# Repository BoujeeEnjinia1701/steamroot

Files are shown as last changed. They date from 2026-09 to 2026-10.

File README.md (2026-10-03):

# SteamRoot

     

**Area:** Agriculture · **TRL:** 3 of 9 (analytical proof of concept on paper) · **Value-engineering target:** USD 2,200 (estimated cost USD 2,600) · **Difficulty:** 5 of 5

Low-pressure, biomass-fired steam generator with a flue-gas economizer and a steam-hood trailer for soil pasteurization, operated near atmospheric pressure to stay out of pressure vessel code.

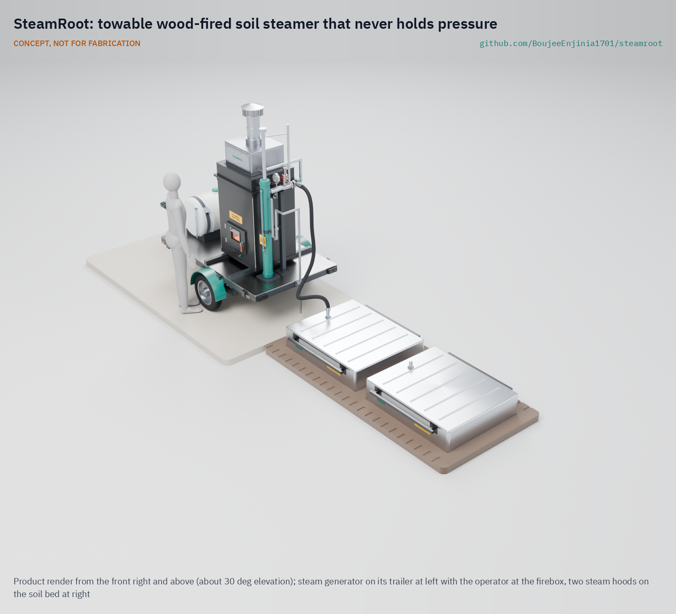
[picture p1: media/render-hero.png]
SteamRoot: towable wood-fired soil steamer that never holds pressure, product render


[Exploded render](media/render-exploded.png) · [Detail render](media/render-detail.png) · [Interactive 3D model](media/viewer.html) · [Concept blueprint (PDF)](media/concept-blueprint.pdf) · [General arrangement STR-DWG-002 (PDF)](cad/drawings/STR-DWG-002.pdf) · [Sizing calculations](docs/04-calcs/01-sizing.md) · [Prototype build plan](docs/05-build-plan.md) · [Design decisions](docs/06-design-decisions.md) · [Review note](docs/REVIEW.md)

## Concept rationale

Steam is the one soil treatment that kills weed seeds and soil-borne pathogens in hours, in any season, with nothing left behind in the soil. What keeps it away from small growers is the boiler: a pressurized, diesel- or gas-fired vessel that is costly, regulated and dangerous to improvise. SteamRoot removes the pressure instead of managing it. A once-through coil holds about 7 L of water and is always open to the air through a water seal, so there is no drum to rupture, and the fire burns the prunings and scrap wood that most farms already have.

The design is open and garage-buildable because the users are market gardens, nurseries and cooperatives that cannot justify a commercial steamer for a few hundred square meters of beds. Stock steel, stainless tube, a used trailer and certified off-the-shelf safety parts keep it inspectable and repairable, and publishing the calculations lets extension services and local boiler authorities check exactly how it stays near atmospheric pressure.

## Burning platform

Weeds are the costliest pest group in farming: a global review found they cause the highest potential crop loss of any pest group, about 34 % ([Oerke, *Journal of Agricultural Science*, 2006](https://www.cambridge.org/core/journals/journal-of-agricultural-science/article/abs/crop-losses-to-pests/AD61661AD6D503577B3E73F2787FE7B2)). Growers who avoid synthetic herbicides are a large and growing group: certified organic land reached 98.9 million hectares at the end of 2023, managed by 4.3 million producers ([FiBL and IFOAM, *The World of Organic Agriculture 2025*](https://www.fibl.org/en/info-centre/news/organic-market-back-on-track)).

The chemical fallback is closing. Methyl bromide, long the standard soil fumigant, was phased out under the Montreal Protocol; in the United States, California strawberry fields were the last pre-plant use to receive a critical use exemption, for 2016, and no pre-plant use was nominated for 2017 ([US EPA, 80 FR 61985, 2015](https://www.federalregister.gov/documents/2015/10/15/2015-26301/protection-of-stratospheric-ozone-the-2016-critical-use-exemption-from-the-phaseout-of-methyl)). Steam is an effective replacement, but only if its energy cost per square meter comes down.

## Where it could be used

### By industry

| Industry | Use |
| --- | --- |
| Organic market gardening | Clearing weed seed banks from high-value vegetable beds before planting |
| Nurseries and seedling propagation | Pasteurizing potting media and propagation beds against damping-off |
| Greenhouse and polytunnel horticulture | Steaming soil between crops, with the generator kept outside |
| Cut flowers and ornamentals | Soil treatment for field-grown flowers where fumigants are no longer allowed |
| Agricultural extension and research | An open reference design for field days, trials and teaching |
| Community gardens and urban farms | A shared, towable machine for plots too small for contract steaming |

### By country or region

| Country or region | Why it matters there |
| --- | --- |
| United States (California) | High-income strawberry and vegetable growers lost the last pre-plant methyl bromide exemption after 2016 ([US EPA, 2015](https://www.federalregister.gov/documents/2015/10/15/2015-26301/protection-of-stratospheric-ozone-the-2016-critical-use-exemption-from-the-phaseout-of-methyl)) |
| Mexico | Steam has already replaced methyl bromide in the ornamental plant sector, where growers pasteurize media before planting ([UNEP, 2014](https://ozone.unep.org/system/files/documents/Phasing-out%20Methyl%20Bromide%20in%20developing%20countries%20FINAL%20low%20version.pdf)) |
| India | Home to 2.36 million organic producers, more than half the world total ([FiBL, 2025](https://www.fibl.org/en/info-centre/news/organic-market-back-on-track)) |
| Kenya | Substrates replaced methyl bromide in Kenyan rose production; growers who stay in soil, and nursery beds, still need a clean soil treatment ([UNEP, 2014](https://ozone.unep.org/system/files/documents/Phasing-out%20Methyl%20Bromide%20in%20developing%20countries%20FINAL%20low%20version.pdf)) |
| Egypt and Jordan | Methyl bromide phase-out projects there used soil solarization, which needs the hot season; steam works year-round ([UNEP, 2014](https://ozone.unep.org/system/files/documents/Phasing-out%20Methyl%20Bromide%20in%20developing%20countries%20FINAL%20low%20version.pdf)) |

## What sparked the idea

The idea traces back to the Montreal Protocol's phase-out of methyl bromide as a soil fumigant, completed on 1 January 2005 in developed countries and on 1 January 2015 in developing ones. Reviewing that phase-out in 2014, UNEP's Ozone Secretariat called steam "probably the best technical alternative to MB in protected agriculture", but warned that deep in-ground steaming needs so much boiler time, labor and fuel that it "may render steaming an economically unacceptable alternative" ([UNEP, *Phasing-out Methyl Bromide in Developing Countries*, 2014](https://ozone.unep.org/system/files/documents/Phasing-out%20Methyl%20Bromide%20in%20developing%20countries%20FINAL%20low%20version.pdf)). SteamRoot starts from that gap: keep the steam, and cut the boiler cost, the fuel bill and the pressure hazard.

## Problem

Herbicide-free weed and pathogen control by steaming soil works, but the portable boilers that do it are inefficient and diesel-fired.

## Concept

Low-pressure, biomass-fired steam generator with a flue-gas economizer and a steam-hood trailer for soil pasteurization, operated near atmospheric pressure to stay out of pressure vessel code.

Full design precis: [docs/02-concept.md](docs/02-concept.md)

TRL 3 status (paper only): the sizing note [STR-CAL-001](docs/04-calcs/01-sizing.md) finds 30 kg/h of steam at a header pressure of about 0.03 bar with 7.3 L of water in the heated section, about 1.9 m²/h treated at 15 cm with two hoods and 499 kg as towed with the tank drained and both hoods aboard. With the evaporator bank and the primary and secondary air dampers decided on 2026-10-02, fuel-to-steam efficiency is about 69 % against the 65 % target (about 61 % if the dampers are left open) and wood use is 4.2 kg per m² against 4. Value-engineering target: USD 2,200. Estimated cost of the constructable design: USD 2,600 (USD 400 over the target). A written ruling from the local boiler authority is an open prerequisite before any detail design or build. TRL 4 work is on hold.

## Key components

- Once-through monotube coil, 25.4 mm 316 stainless
- Fiber-lined firebox
- Evaporator bank and economizer in the flue, with primary and secondary air dampers
- Fixed-rate feed pump with coil outlet and tank level alarms
- Water-seal vent with an overflow and loop seal, and a certified relief valve
- Two steam hoods used alternately
- Thermocouples

The working bill of materials is in [bom/bom.csv](bom/bom.csv).

## Building the prototype

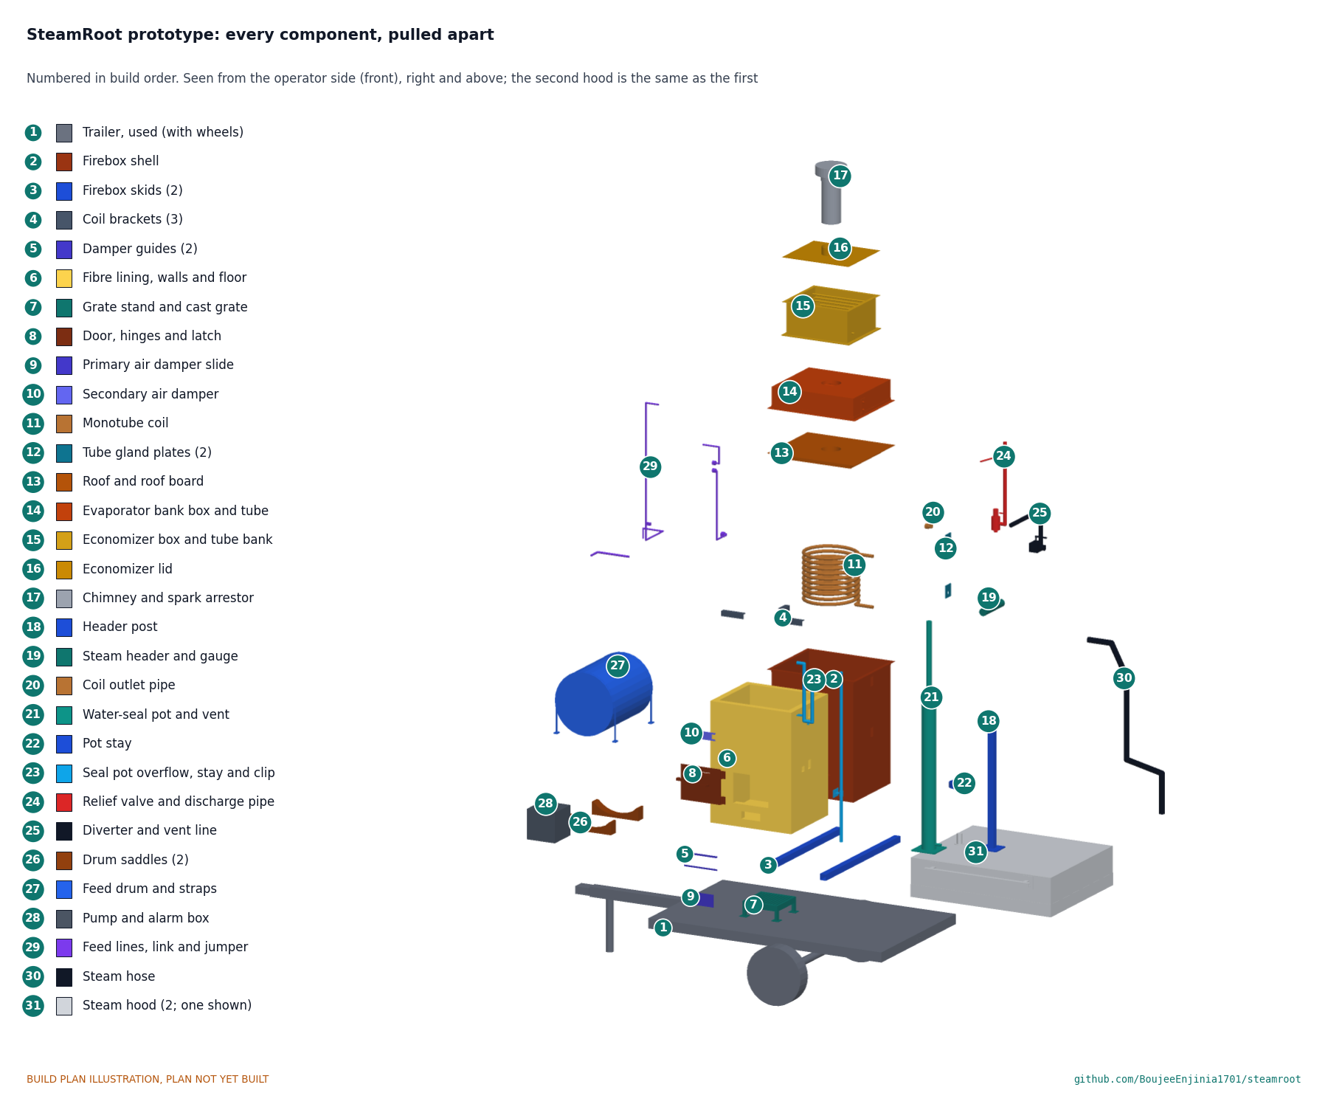
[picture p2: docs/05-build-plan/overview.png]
SteamRoot prototype: every component pulled apart and numbered in build order


The [prototype build plan](docs/05-build-plan.md) (STR-BLD-001) shows, in pictures, how to make each of the 31 components and put them together in twenty steps; nothing has been built, and nothing may be until the local boiler authority has given its written ruling. The firebox, roof, skids, brackets, grate stand, door, dampers, evaporator bank box, economizer, header, post, seal pot and overflow are cut and welded from mild steel and stainless sheet, tube and pipe; the coil and the evaporator bank are each bent from one length of stainless tube; the hoods are folded and riveted. Writing the plan made the design buildable: the firebox grew to about 1 m so the door and fire sit below the coil, the roof now bolts on so the coil can be fitted, the seal pot's dip leg was shortened, and supports, glands, feed lines and a vent line were added (STR-DDR-003, accepted by Amish on 2026-10-02). The decisions of 2026-10-02 then added the evaporator bank box, the secondary air damper, a seal pot overflow that holds the seal limit at 0.084 bar, and hood handles that can carry ballast. Every picture is drawn from the model, and the model checks that each part touches what it should and clears what it should not; open decisions are in the [design decisions register](docs/06-design-decisions.md).

## Safety

> This design involves open fire, carbon monoxide and steam. Keep operating pressure and water volume below local boiler and pressure vessel code thresholds, get a written ruling from the local boiler authority before any build, fit a certified relief valve, and never operate it unattended.

## Repository layout

| Folder | Contents |
| --- | --- |
| `docs/` | Problem, concept, requirements, calculations and design decisions |
| `cad/src/` | build123d Python source, the source of truth for all geometry |
| `cad/step/`, `cad/stl/` | Exported models for FreeCAD, other CAD tools and printing |
| `cad/drawings/` | 2D sketches and dimensioned drawings |
| `bom/` | Bill of materials |
| `electronics/` | KiCad schematics and PCB layouts |
| `firmware/` | Microcontroller code |
| `media/` | Renders, perspectives and photos |
| `build-log/` | Dated prototyping notes |

## Documentation

Controlled documents follow the portfolio [documentation standard](.kit/STANDARDS.md). Each carries a document ID (STR-PRC-001 for the precis), a version and a revision history. Branded PDFs are built with `python .kit/render.py` and attached to GitHub Releases when a document is tagged, for example `STR-PRC-001/v1.0`.

## Credits

Designed by Amish Chadha. See [CONTRIBUTORS.md](CONTRIBUTORS.md) for roles. To cite this design, use [CITATION.cff](CITATION.cff) (GitHub shows it as "Cite this repository").

AI assistance (Claude) was used to accelerate concept renders, prototype documentation and first-pass sizing calculations. Design direction and all decisions are Amish Chadha's, recorded in this repository's decision records (`docs/decisions/`).

## Licenses

- **Hardware** (CAD, drawings, BOM, electronics): [CERN-OHL-S v2](LICENSE)
- **Software** (firmware, scripts, notebooks): [MIT](LICENSE-SOFTWARE)

A project of the [Design Molecule](https://designmolecule.com) lab.

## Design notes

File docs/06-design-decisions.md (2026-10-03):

---
doc_id: STR-DEC-001
title: SteamRoot design decisions register
project: SteamRoot
doc_type: Design decisions register
version: "0.4"
status: Draft
date: '2026-10-03'
author: Amish Chadha
license: CERN-OHL-S-2.0
revisions:
- version: "0.1"
  date: '2026-10-01'
  author: Amish Chadha
  change: Register opened with the open decisions from the review notes, the decision records and the build plan work; budget treated as a value-engineering target
- version: "0.2"
  date: '2026-10-02'
  author: Amish Chadha
  change: "Amish approved the recommendations for all eleven open decisions on 2026-10-02 (STR-DDR-003 accepted); moved to decisions made"
- version: "0.3"
  date: '2026-10-02'
  author: Amish Chadha
  change: "Approved decisions carried into the design (STR-CAL-001 v0.4); value engineering restated at USD 2,600; two new proposals opened: R4 restatement and the R11 mass basis"
- version: "0.4"
  date: '2026-10-03'
  author: Amish Chadha
  change: "Amish accepted the cost overrun against the value-engineering target on 2026-10-03; row added to decisions made; value engineering section updated"
---

# SteamRoot design decisions register

Every design decision still to be made, and every decision made, in one place. Each decision is argued in full in its decision record under `docs/decisions/`; this register is the index Amish works from. The build plan (`docs/05-build-plan.md`) describes the design as it stands and does not list open decisions.

> **Safety:** Decision 1 gates everything else. No part of SteamRoot may be bought, built or fired before the written ruling from the local boiler authority exists, and that ruling overrides any decision here that it is stricter than.

## Open decisions

The eleven decisions of the 2026-10-02 sign-off are made. Carrying them into the design raised two new questions, proposed here and awaiting Amish.

| # | Question | Options | Recommendation | Source |
| --- | --- | --- | --- | --- |
| 12 | Restate R4 (wood per m² at 15 cm), as planned on 2026-10-02. With the bank and dampers the design uses 4.2 kg/m² (4.7 kg/m² with the dampers open); 4 kg/m² needs about 72 % efficiency. | (a) 4.5 kg/m² or less with the dampers set; (b) 5.0 kg/m² or less, which also covers open dampers; (c) keep 4 kg/m² and seek the rest in lower steam demand | (a): met with 7 % margin and still rewards air control. Proposed, awaiting Amish | STR-CAL-001 v0.4, section 4 |
| 13 | R11 is now at risk at 499 kg as towed, because the bank, overflow and steel handles added 36 kg. The hoods ride on a second vehicle for the prototype (decided 2026-10-02). | (a) count R11 without the hoods, as they are towed: 437 kg; (b) keep the hoods in R11 and save mass elsewhere (lighter bank box, aluminium skids); (c) restate R11 | (a), since it follows the decision already made; record it in STR-REQ-001. Proposed, awaiting Amish | STR-CAL-001 v0.4, section 7 |

## To confirm when parts are bought

| # | What to confirm | Why it matters | Source |
| --- | --- | --- | --- |
| 1 | The used trailer: rated 750 kg or more, axle rated for the 633 kg full mass, and side rails that take an M12 bolt 40 mm in from the deck edge (80 mm rails assumed) | The skids bolt into the side rails; the full machine weighs 602 kg on site | STR-DDR-003, C5; STR-CAL-001 |
| 2 | The relief valve's rated capacity, 375 lb/h (170 kg/h) or more at 15 psi, on the valve actually bought, with its code stamp | R9 is met only on the maker's table | STR-DDR-002, item 4 |
| 3 | The three-way diverter cannot stop in a position that closes both outlets, and is rated for saturated steam | The open vent must never be isolated | STR-PRC-001; STR-DDR-003, C8 |
| 4 | The steam hose and couplings are rated for saturated steam (not hot water), with whip checks | Burn hazard at the hose | BOM line 11 |
| 5 | The cast grate is 300 x 300 mm; if not, the grate stand is resized to suit | The stand is made to the grate | STR-DDR-003, C1 |
| 6 | The ceramic fibre blanket and board are rated for 1260 °C, with rigidizer for the walls | The lining faces the fire | BOM line 5 |
| 7 | The feed pump's shut-off pressure is 3 bar or less | It caps the coil inlet pressure if the coil blocks | STR-CAL-001, section 6 |
| 8 | The alarm controller takes a type K thermocouple and drives a relay; the float switch trips with about 20 L left | The dry-coil and low-tank alarms | BOM line 16 |

## Value engineering

Value-engineering target: USD 2,200 (a hypothetical control target, not a limit). Estimated cost of the constructable design: USD 2,600 (USD 400 over the target). Main cost drivers and savings worth trying:

Amish accepted this overrun on 2026-10-03: the estimated cost of USD 2,600 against the USD 2,200 target (USD 400 over). Amish: "Cost over target - i accept all the cost variations and overruns". It stays reported against the target as an accepted overrun, and the savings below remain worth trying.

- The largest lines are the two hoods (USD 310 together), the firebox (USD 265), the header and water-seal assembly with its overflow (USD 220), the stainless coil (USD 215), the used trailer (USD 200), the evaporator bank (USD 190) and the steam hose (USD 180).
- Carrying the 2026-10-02 decisions into the design added USD 325: the evaporator bank (USD 190), the seal pot overflow (USD 70), the bank link and reducing unions (USD 45), ballast-rated hood handles (USD 30), the secondary damper and fixings (USD 10 net), less USD 20 for one coil turn fewer.
- Making the design constructable added USD 360: the taller firebox and longer coil (USD 55), steelwork for the skids, post, stay and saddles (USD 70), firebox internals and glands (USD 50), feed lines and stainless fittings (USD 95), the relief discharge and vent line (USD 45) and fixings and straps (USD 45).
- Savings worth trying: copper instead of stainless for the cold feed line from the pump (about USD 20; the economizer and jumper stay stainless); offcut or reclaimed steel for the skids, post and stand; buying the stainless fittings from one supplier as a kit; a used trailer that already has cross members for the skids; welded rather than seamless 316 tube for the bank (already assumed); a bank box with 1.5 mm walls. The safety parts (relief valve, diverter, hose, seal and vent) are not candidates for savings.

## Decisions made

| Date | Decision | Decided by | Record |
| --- | --- | --- | --- |
| 2026-09-25 | Open-vented steam side with a water-seal vent and a certified relief valve, no isolating valve; 25.4 mm 316 stainless monotube coil; two hoods used alternately; fixed-rate feed with coil outlet and tank level alarms; budget USD 1,800; first users one market garden and one nursery, first jurisdiction Amish's home jurisdiction; get the boiler authority ruling first | Amish: "proceed with all of your recommendations across all batches. Make sure we don't proceed to TRL 4 on any of them." | STR-DDR-001 |
| 2026-09-25 | Wood only, no liquid fuel backup | Amish: go with recommendation | STR-DDR-001, item 10; STR-DDR-002, item 9 |
| 2026-09-25 | Keep the R5 and R4 targets and study an evaporator bank with controlled air; R2 restated to about 1.9 and 3.4 m²/h; R6 split into 0.1 bar at the header and 0.15 bar at the coil inlet; R9 worded as 15 psi (1.03 bar) or less and sized for the refeed flash; R11 as towed with the drum drained; budget USD 2,200; fibre lining; one hose moved between the hoods | Amish: "i accept all your recommendations, go with them across all repos." | STR-DDR-002, items 1 to 8 |
| 2026-10-01 | The budget is a value-engineering target, not a limit; cost is reported over or under it | Amish: "the budgets are a hypothethical control target to ensure we are thinking along a value engineering lens. its ok to ensure wording reflects that the hypothesis budget was x - the real cost being accrued is y" | This register; STR-CAL-001 v0.3 |
| 2026-10-02 | The written ruling stays the gate: it is obtained before any purchase or build, the design is reviewed against it, and anything stricter it requires is adopted (the ruling itself is not yet obtained) | Amish: "i approve your recommendations for all 555 open decisions." | STR-DDR-001, item 7; STR-DDR-002, item 10 |
| 2026-10-02 | Home jurisdiction: Texas. The written ruling is asked of the Texas Department of Licensing and Regulation's boiler program | Amish: "i approve your recommendations for all 555 open decisions." | STR-DDR-002, item 11 |
| 2026-10-02 | First co-design partners: one market garden and one nursery within driving distance of Irving that already steam, solarize or chemically treat soil, found through Texas A&M AgriLife Extension's horticulture contacts (none is named or agreed yet) | Amish: "i approve your recommendations for all 555 open decisions." | STR-DDR-002, item 12 |
| 2026-10-02 | In the next paper iteration, size the evaporator bank with primary and secondary air dampers so the heated water stays at 8 L or less (smaller-bore bank tube or fewer firebox turns), without relaxing R7; plan to restate R4, since even 65 % efficiency leaves it short (about 72 % needed) | Amish: "i approve your recommendations for all 555 open decisions." | STR-DDR-002, item 1 |
| 2026-10-02 | Option (c), keeping (a) for now: the taller firebox's 51.4 % is accepted for the first prototype, and the firebox is reshaped inside the evaporator bank study | Amish: "i approve your recommendations for all 555 open decisions." | STR-DDR-003, A1 |
| 2026-10-02 | Seal pot overflow at the static water mark, piped down to ground level at the back of the trailer away from the operator's side | Amish: "i approve your recommendations for all 555 open decisions." | STR-DDR-003, A2; STR-PRC-001 open questions |
| 2026-10-02 | Relief valve discharge kept rising to 2.3 m beside the vent, with its low-point drain, subject to the authority's ruling | Amish: "i approve your recommendations for all 555 open decisions." | STR-DDR-003, A3 |
| 2026-10-02 | Seal pot drained through its valve after every day of use and whenever frost is forecast; a pre-start check that the pot is free of ice and filled to its mark | Amish: "i approve your recommendations for all 555 open decisions." | STR-PRC-001 open questions |
| 2026-10-02 | The two hoods ride on a second vehicle for the prototype | Amish: "i approve your recommendations for all 555 open decisions." | STR-PRC-001 open questions |
| 2026-10-02 | Design for construction accepted: changes C1 to C14 of STR-DDR-003 as made, with the seal pot overflow decided separately (item 6) | Amish: "i approve your recommendations for all 555 open decisions." | STR-DDR-003 |
| 2026-10-02 | Hood ballast, skirt depth or steam rate decided from TRL 4 soil tests, with skirt leakage measured at the hood edge; the hood handles are sized to take ballast weights so no redesign is needed later | Amish: "i approve your recommendations for all 555 open decisions." | STR-CAL-001, section 2; STR-PRC-001 open questions |
| 2026-10-03 | Cost overrun accepted: the estimated cost of USD 2,600 against the USD 2,200 target (USD 400 over) | Amish: "Cost over target - i accept all the cost variations and overruns" | [REVIEW.md](REVIEW.md), session 2026-10-03 |

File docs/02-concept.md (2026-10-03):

---
doc_id: STR-PRC-001
title: SteamRoot design precis
project: SteamRoot
doc_type: Design precis
version: "0.7"
status: Draft
date: '2026-10-02'
author: Amish Chadha
license: CERN-OHL-S-2.0
revisions:
- version: "0.1"
  date: '2026-09-24'
  author: Amish Chadha
  change: Initial scaffold
- version: "0.2"
  date: '2026-09-24'
  author: Amish Chadha
  change: Populate to TRL 2 (architecture, components, first-order numbers, safety, media)
- version: "0.3"
  date: '2026-09-25'
  author: Amish Chadha
  change: TRL 3 update; record Amish's 2026-09-25 decisions; replace first-order numbers with STR-CAL-001 results; water-seal pot, two hoods and alarms added; regulatory ruling marked as an open prerequisite
- version: "0.4"
  date: '2026-09-25'
  author: Amish Chadha
  change: Recommendations accepted by Amish (DDR-002)
- version: "0.5"
  date: '2026-10-01'
  author: Amish Chadha
  change: Figures and description updated for the constructable design (STR-DDR-003, STR-CAL-001 v0.3); cost against the value-engineering target; build plan and decisions register linked
- version: "0.6"
  date: '2026-10-02'
  author: Amish Chadha
  change: "Decisions of 2026-10-02: authority named, first co-design partner route, seal pot overflow and freezing rule, hoods on a second vehicle, evaporator bank study scope, hood ballast from TRL 4 tests"
- version: "0.7"
  date: '2026-10-02'
  author: Amish Chadha
  change: "Approved decisions carried into the design (STR-CAL-001 v0.4): evaporator bank and secondary air damper added, firebox 960 mm with 10 coil turns, seal pot overflow with loop seal (seal limit 0.084 bar), ballast-rated hood handles; figures and requirement status updated"
---

# SteamRoot design precis

SteamRoot is a towable, wood-fired steam generator that never holds pressure. A pump pushes water once through an economizer, an evaporator bank in the flue and a large-bore stainless coil above the fire, the steam flows at close to atmospheric pressure through a hose to one of two insulated hoods pressed onto the soil, and primary and secondary air dampers hold the excess air near 1.5. The TRL 3 calculation (STR-CAL-001 v0.4) confirms the core safety idea on paper: 30 kg/h of steam with 7.3 L of water in the heated section and a header pressure of about 0.03 bar. With the evaporator bank and dampers decided on 2026-10-02, fuel-to-steam efficiency is about 69 % (target 65 %, met if the dampers are set) and wood use 4.2 kg per m² at 15 cm (target 4, at risk; a restatement to 4.5 is proposed). It treats about 1.9 m²/h at 15 cm with two hoods and weighs 499 kg as towed with the tank drained and both hoods aboard. Value-engineering target: USD 2,200. Estimated cost of the constructable design: USD 2,600 (USD 400 over the target). The design was made constructable on 2026-10-01 (STR-DDR-003, accepted by Amish on 2026-10-02); the prototype build plan is [docs/05-build-plan.md](05-build-plan.md) and open decisions are in [docs/06-design-decisions.md](06-design-decisions.md).

> **Safety:** SteamRoot is a concept for review, not a design to build. It combines open fire, carbon monoxide, and steam that causes severe burns in under a second. Local boiler and pressure vessel rules may apply even at low pressure. **A written ruling from the local boiler authority is an open prerequisite:** Amish approved getting it before TRL 3 detail work, and it has not been obtained. See the Safety section before any further work.

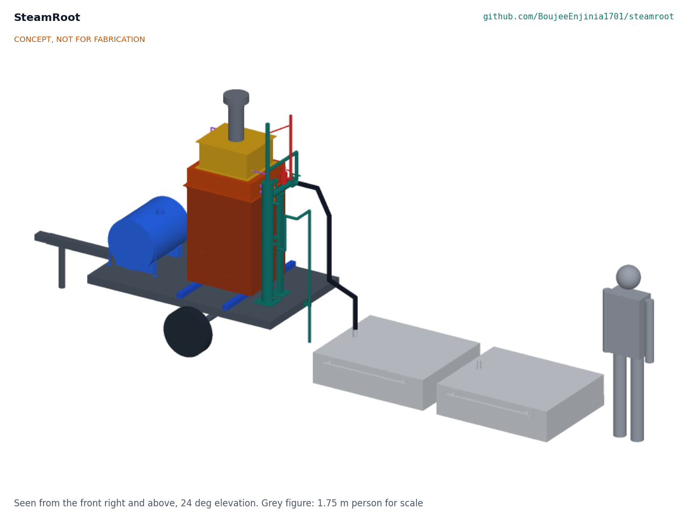
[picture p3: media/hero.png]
Hero render


*Figure 1. TRL 3 model in the working position: trailer, generator and two hoods on a bed, next to a 1.75 m person.*

## How it works

1. **Feed.** A 12 V diaphragm pump draws water from a 125 L tank and meters 0.5 L/min (30 kg/h) into the economizer at a fixed rate. A float switch warns when the tank runs low.
2. **Preheat and start to boil.** The economizer coil sits at the top of the flue and warms the feed water from about 15 °C to about 65 °C. The water then passes down through an evaporator bank, a serpentine of 15.88 mm stainless tube in a lined box on the firebox roof, where the hotter gas leaving the firebox brings it to the boil.
3. **Boil.** The warm water enters the bottom of a monotube coil that sits above the fire bed inside the fiber-lined firebox, on three brackets, with the door, grate and the two air inlets below it: primary air under the grate and secondary air through a slot in the door above the fire bed. It boils as it rises through 10 turns and leaves the top of the coil as steam. The coil holds about 5 L of water. A thermocouple on the coil outlet sounds an alarm if the outlet overheats, which is the sign of a coil running dry.
4. **Vent and separate.** The coil discharges into a steam header 1.55 m above the ground. The header is always open to the atmosphere through a water-seal pot: a dip leg reaches 890 mm below the water line. An overflow at the static water mark, piped through a 350 mm loop seal down to ground level at the back of the trailer away from the operator's side (decided by Amish, 2026-10-02), stops the pot being overfilled and lets the water the dip leg displaces run away. Steam can therefore build only about 0.084 bar gauge (890 mm of water) before it bubbles through the seal and out of a vent pipe that ends 2.3 m above the ground, above head height. The seal cannot stick or be adjusted, and it is never valved off. A certified relief valve on the header is the second line of protection.
5. **Deliver.** Steam flows through a 6 m, 25 mm steam hose to a hood. A three-way diverter at the header sends steam to the hose or to the vent and has no closed position.
6. **Pasteurize.** Each hood is a 1.2 x 1.0 m insulated open-bottom pan with a 60 mm soil skirt. Steam from a perforated manifold condenses in the soil and drives a hot front downward. While one hood heats, the other holds its soil at temperature. To change over, the operator diverts steam to the vent, moves the hose coupling to the other hood and diverts steam back.

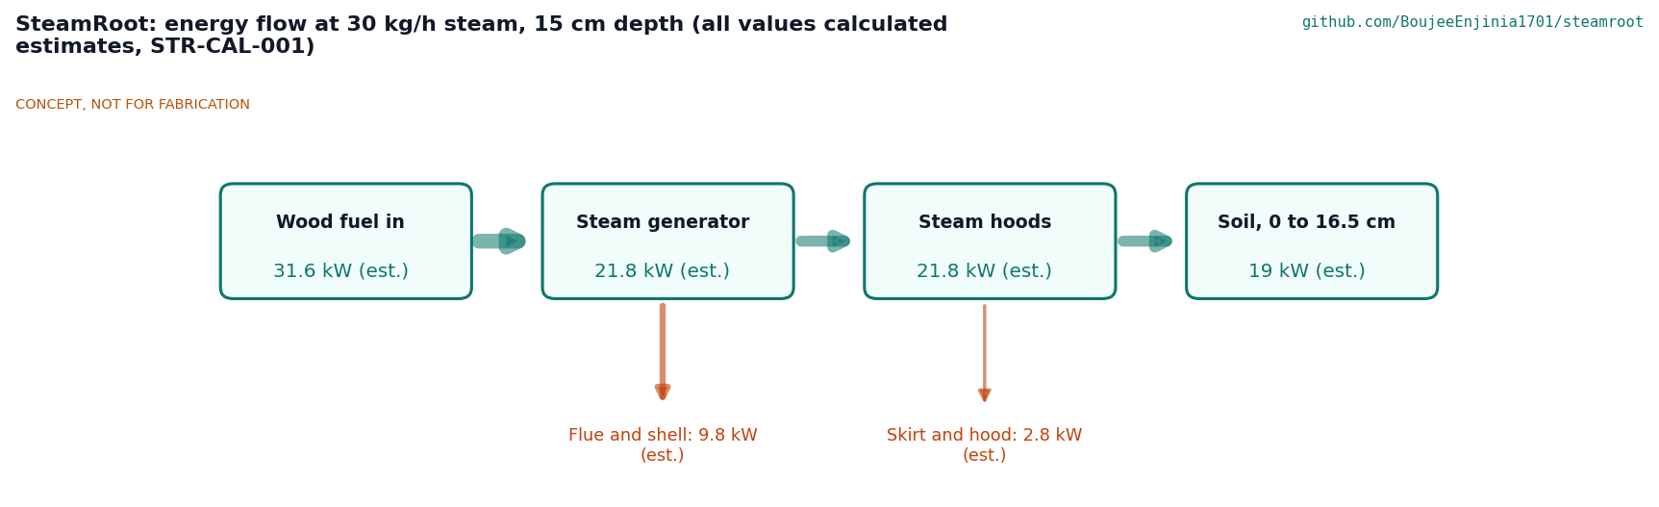
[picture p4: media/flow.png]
Energy flow


*Figure 2. Energy flow at the design point of 30 kg/h of steam and 15 cm depth. All values are calculated estimates from STR-CAL-001.*

## Main components

Item numbers match the exploded view, the general arrangement drawing STR-DWG-002 and `bom/bom.csv`. Items 13 to 16 are not drawn.

*Table 1. Main components.*

| # | Component | Choice | Notes |
| --- | --- | --- | --- |
| 1 | Trailer frame and drawbar | Used single-axle garden or utility trailer, deck 2.0 x 1.2 m | Rated 750 kg or more |
| 2 | Wheels | Trailer wheels, about 460 mm diameter | Included with the trailer |
| 3 | Feed water tank | 125 L HDPE drum with strainer and sight tube | 4.2 h of steaming |
| 4 | Feed pump | 12 V diaphragm pump with needle valve and flow meter | Its 3 bar shut-off pressure also caps coil inlet pressure if the coil blocks |
| 5 | Firebox | 700 x 600 x 960 mm steel box on two skids, bolted roof, 50 mm ceramic fiber lining, grate on a stand, latched door, primary air damper under the door and secondary air slide on the door | About 32 kW firing. A castable lining would add about 270 kg |
| 6 | Monotube steam coil | 316 stainless tube, 25.4 mm OD x 1.65 mm wall, 13.2 m in 10 turns on 420 mm | Decided by Amish, 2026-09-25; one turn fewer since 2026-10-02 to keep R7 |
| 22 | Evaporator bank | 6.4 m of 15.88 mm x 1.24 mm 316 stainless tube in two layers, in a lined 700 x 600 x 170 mm box between the roof and the economizer | Decided 2026-10-02; lifts efficiency to about 69 % with the dampers set |
| 7 | Flue-gas economizer | 7.3 m of 12.7 mm stainless tube in a box on the bank box, with condensate drain | Flue condensate is acidic (dew point about 51 °C) |
| 8 | Chimney and spark arrestor | 150 mm flue, outlet 2.4 m above ground, 6 mm mesh | Keeps flue gas above head height |
| 9 | Steam header and water-seal vent | DN50 header at 1.55 m on a post, 114 mm seal pot with an 890 mm dip leg, an overflow at the static water mark through a loop seal to the ground behind the trailer, vent to 2.3 m, three-way diverter with a vent line, quick coupling | Primary pressure limit. Decided by Amish, 2026-09-25 |
| 10 | Certified relief valve | ASME Section IV steam safety valve, 15 psi (1.03 bar) set, 3/4 in, rated 170 kg/h (375 lb/h) | Secondary protection only; sized for the dry-coil refeed flash (decided by Amish, 2026-09-25) |
| 11 | Steam hose | EPDM saturated-steam hose, 25 mm bore, 6 m, ground-joint couplings, whip checks | Steam rated, not hot-water rated |
| 12 | Steam hoods (2) | 1.2 x 1.0 x 0.25 m aluminum double-skin pans, 40 mm mineral wool, soil skirt, steel handles on foot plates sized for 40 kg of ballast | Two hoods used alternately. Decided by Amish, 2026-09-25 |
| 13 | Battery | 12 V 20 Ah sealed lead acid | Not drawn |
| 14 | Instruments | Steam gauge, four type K thermocouples and reader | Soil probes at 15 cm; not drawn |
| 15 | Safety kit | Personal CO alarm, fire extinguisher, gloves, face shield | Not drawn |
| 16 | Feed and coil alarms | Coil outlet temperature alarm, tank low-level switch | Decided by Amish, 2026-09-25; not drawn |

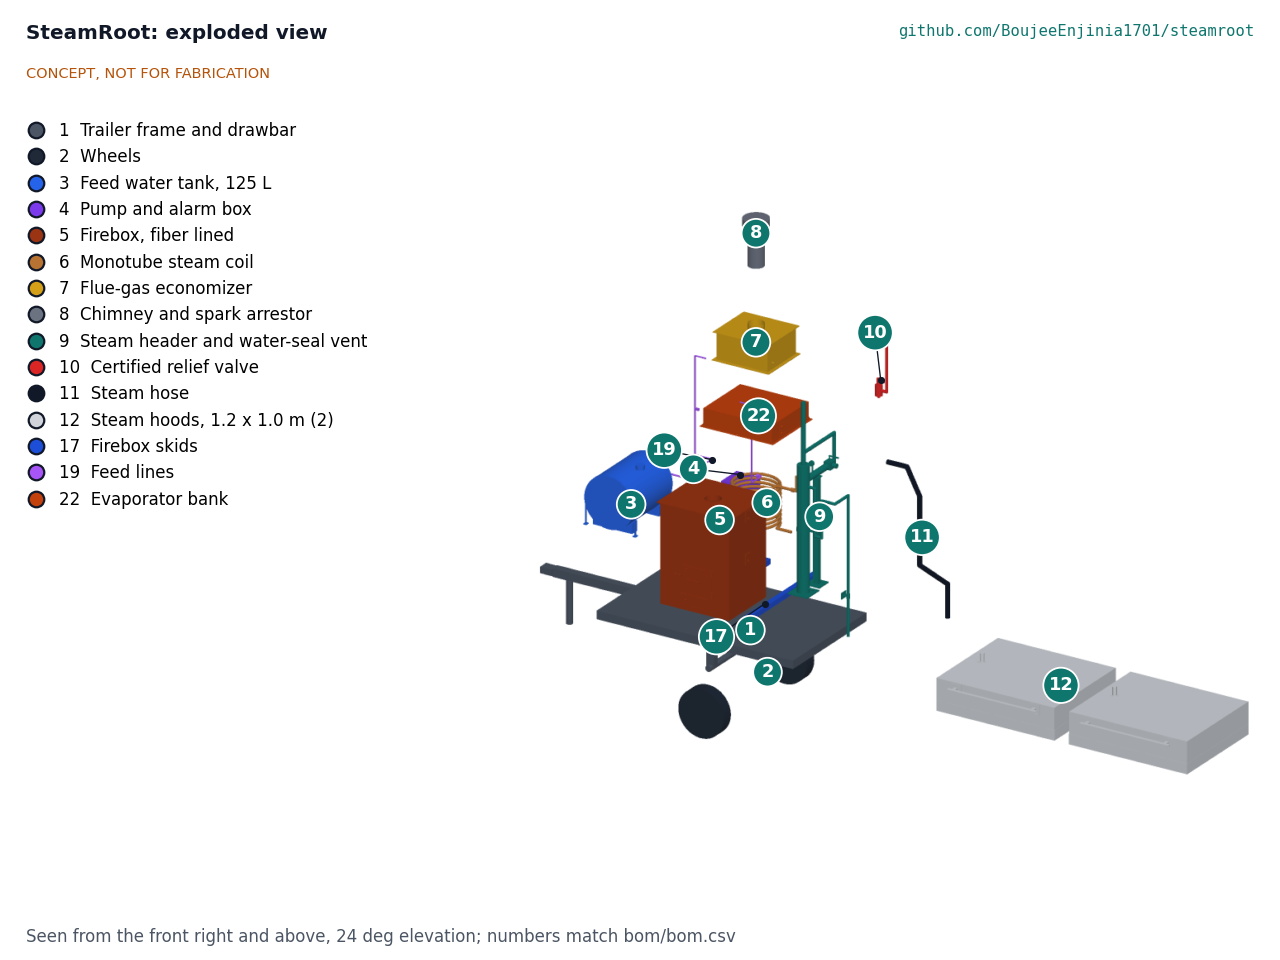
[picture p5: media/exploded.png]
Exploded view


*Figure 3. Exploded view with item numbers matching the BOM.*

## TRL 3 numbers

All values come from STR-CAL-001 (`docs/04-calcs/01-sizing.md`, script `docs/04-calcs/sizing.py`). They are paper estimates; none is tested.

*Table 2. Key results.*

| Quantity | Value | Requirement |
| --- | --- | --- |
| Steam output | 30 kg/h, firing 31.6 kW, firebox gas 510 °C | R3 met |
| Heat into the water | 21.78 kW (coil 16.91 kW, bank 3.14 kW, economizer 1.73 kW) | |
| Fuel to steam efficiency | 68.9 % at λ = 1.5 (66 % to 71 % for F = 0.25 to 0.60; 61 % with the dampers open; see STR-CAL-001, Table 6) | R5 met on paper if the dampers are set |
| Stack temperature | 235 °C | |
| Wood use | 7.9 kg/h at 14.5 MJ/kg | |
| Steam per m² at 15 cm | 15.6 kg/m² (front to 16.5 cm) | |
| Treatment rate, two hoods | 1.88 m²/h at 15 cm; 3.41 m²/h at 5 cm | R2 at risk (restated to about 1.9 and 3.4 m²/h) |
| Wood per m² at 15 cm | 4.2 kg/m² (4.7 kg/m² with the dampers open) | R4 at risk; restatement to 4.5 kg/m² proposed, awaiting Amish |
| Header pressure, normal | 0.033 bar gauge | R6 met (0.1 bar at the header) |
| Coil inlet pressure, normal (at the bank inlet) | 0.128 bar gauge | R6 met (0.15 bar at the coil inlet) |
| Water seal limit | 0.084 bar gauge with the overflow | R6 open vent met by design |
| Water in heated section, flooded | 7.32 L | R7 met |
| Steaming per fill | 4.2 h | R8 met |
| Relief valve orifice needed | 6.2 mm at 30 kg/h; 13.3 mm for a dry-coil refeed flash (138 kg/h); 3/4 in valve rated 170 kg/h | R9 met on paper |
| Chimney outlet, hood outer skin | 2.4 m; 23 °C | R10 met |
| Mass as towed, tank and seal drained | 499 kg with both hoods aboard (633 kg full; 437 kg with the hoods on a second vehicle) | R11 at risk |
| Overall width | 1.48 m | R11 at risk |
| Parts cost | USD 2,600 | USD 400 over the USD 2,200 value-engineering target |

The main performance gap was heat transfer. One coil in the firebox takes heat mostly by radiation, and without the bank the flue gas left the economizer at about 450 °C. Amish decided on 2026-09-25 to keep the 65 % target and study a convective evaporator bank with controlled air, and on 2026-10-02 to size it with primary and secondary dampers inside the 8 L limit of R7. The study in STR-CAL-001 v0.4, section 4, found that the dampers alone lift efficiency from 51 % to 61 %, and that a 6.4 m bank of smaller-bore tube with one coil turn fewer reaches about 69 % with 7.3 L of water. Efficiency now depends on the operator keeping the dampers set; with them open it falls to about 61 %. R4 needs about 72 %, so it stays just short at 4.2 kg/m².

The second gap is steam per square meter. Soil behind the steam front sits at 100 °C, not 75 °C, and the front must go 1.5 cm past the working depth to hold 70 °C through the hold. In soils finer than sand, the steam cannot be pushed through 16.5 cm of soil at full flow without lifting a 31 kg hood, so real rates may be lower still. The hood handles are sized to carry 40 kg of ballast if the TRL 4 soil tests call for it.

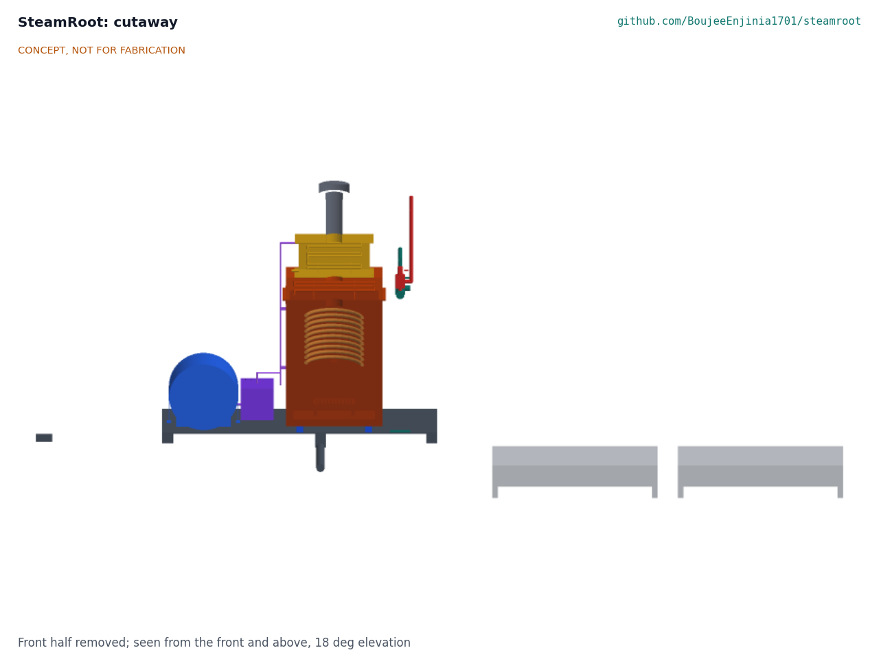
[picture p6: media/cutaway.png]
Cutaway


*Figure 4. Cutaway showing the helical coil above the fire bed inside the fiber-lined firebox, and the open-bottom hoods with their soil skirts.*

## Key design choices

- **Open-vented, never sealed.** The steam side is always open to the atmosphere through the water-seal pot and vent. There is no isolating valve between the coil and the vent, and the diverter can only send steam to the hose or the vent, never close both. Decided by Amish, 2026-09-25.
- **Monotube coil instead of a drum boiler.** A once-through coil and bank hold about 6 L of water, so a failure releases little stored energy. The cost is careful feed control: too little water dries the coil. Decided by Amish, 2026-09-25.
- **Large-bore stainless coil (25.4 mm, 316).** A 12.7 mm coil would need more than 2 bar at its inlet. The 25.4 mm coil keeps the header near 0.03 bar, though the inlet, with the bank ahead of the coil, is at about 0.13 bar. Stainless tolerates a dry-fire event far better than copper. Decided by Amish, 2026-09-25.
- **Hood steaming with two hoods used alternately.** Decided by Amish, 2026-09-25. One hose is moved between the hoods with a steam-rated coupling after steam is diverted to the vent. A second hose and a three-outlet diverter would avoid handling the hose but add at least $180. One hose: decided by Amish, 2026-09-25 (STR-DDR-002).
- **Tow drained, fill on site.** The machine is towed with the feed tank and seal pot drained (499 kg with both hoods aboard) and filled from a water supply at the site. Decided by Amish, 2026-09-25 (STR-DDR-002).
- **Relief valve sized for the refeed flash.** The 3/4 in, 15 psi valve is rated 170 kg/h, above the 138 kg/h a dry-coil refeed could produce. Decided by Amish, 2026-09-25 (STR-DDR-002).
- **Feed control.** Fixed pump rate with a coil outlet temperature alarm and a tank low-level alarm. Decided by Amish, 2026-09-25.
- **Fiber lining, not castable.** A 50 mm ceramic fiber lining keeps the firebox near 125 kg; castable refractory would make it about 406 kg and break R11. Fiber is less robust against loading damage. Fiber lining: decided by Amish, 2026-09-25 (STR-DDR-002).
- **Wood only.** Split wood or chips at 20 % moisture or drier, batch-fed by hand. No liquid fuel backup. Decided by Amish, 2026-09-25 (STR-DDR-002).

## Safety

SteamRoot is the highest-risk concept in the portfolio. Every later stage must keep this section and extend it.

> **Safety: regulatory ruling first.** A written ruling from the local boiler authority (the Texas Department of Licensing and Regulation's boiler program; Amish's home jurisdiction is Texas) on this open-vented, fired monotube coil is an open prerequisite. No detail design, build or firing may happen before it, and its ruling overrides this document if it is stricter.

> **Safety: never sealed.** The steam side must always be open to the atmosphere through the water-seal vent. Never fit a valve, cap or plug that can isolate the coil or header from the vent. Keep the seal pot filled to its mark; an empty seal pot is an open vent, but an overfilled or frozen one raises the relief pressure. The overflow at the static water mark prevents overfilling. Drain the pot through its valve after every day of use and whenever frost is forecast, and before lighting check that the pot is free of ice and filled to its mark (decided by Amish, 2026-10-02). Never plug, adjust or remove the relief valve. A sealed coil or tank over a fire can rupture violently.

> **Safety: certified relief valve.** Fit only a certified, code-stamped steam safety valve sized for the full steam output. It is a second line of protection behind the open vent, not a replacement for it. Test it by its lever as the maker directs.

> **Safety: local boiler rules.** Many jurisdictions regulate steam generators by pressure, heating surface, water volume or firing rate, and some regulate all fired steam equipment. The low-pressure design is intended to stay below common thresholds, but this is unconfirmed. Confirm with the local boiler inspector or authority before any build, and follow their ruling even if it is stricter than this document.

> **Safety: steam burns.** Steam at 100 °C releases its latent heat on skin and causes deep burns within a second. Divert steam to the vent before lifting a hood or moving the hose coupling. In fine soils steam may jet from under the hood skirt, because the soil resists steam flow more than the hood's weight can hold (STR-CAL-001, section 2). Keep hands and feet clear of the skirt and the vent outlet. Wear heat-resistant gloves, a face shield, long sleeves and closed boots. Keep bystanders, children and animals at least 5 m away. Use a steam-rated hose with a whip check, and inspect it before every use.

> **Safety: dry coil.** If the feed pump stops or the tank runs dry, the coil heats toward the firebox gas temperature (about 520 °C) while the fire keeps burning. Refeeding it could flash about 1.3 kg of water at about five times the design steam flow, more than the vent path is sized for. Never restart the feed into a hot, dry coil. Close the air damper, let the fire die and let the coil cool first. The coil outlet alarm and the tank low-level alarm exist to catch this early.

> **Safety: fire.** Operate only on bare ground or gravel, clear of dry vegetation, with a fire extinguisher and water at hand. The spark arrestor must be fitted; the flue leaves at about 450 °C. Do not operate during fire bans or in high wind. Never leave a lit firebox unattended, and let it burn out fully before towing.

> **Safety: carbon monoxide.** Wood fires produce carbon monoxide, which is odorless and deadly. The firebox and chimney must stay outdoors. Steam may be piped into a greenhouse or polytunnel, but the generator may not. The operator wears a personal CO alarm. Never refuel or tend the fire from downwind in the smoke.

> **Safety: hot surfaces and water quality.** The firebox skin reaches about 100 °C, and the chimney, economizer, header, seal pot and hood inner skin reach burn temperatures. Use rain water or softened water to limit scale in the coil; scale raises tube temperature and can block the coil.

- **Soil biology.** Steaming kills beneficial organisms as well as pests, and the soil behind the steam front reaches 100 °C. Overheating soil can release manganese and ammonium that harm seedlings. Do not steam longer than needed.
- **Towing.** Tow only with the fire out and the tank and seal pot drained; the two hoods ride on a second vehicle (decided by Amish, 2026-10-02). Towing with a full tank puts the mass at about 633 kg, over the 500 kg limit in R11.

## Open questions

These are tracked, with options and recommendations, in the design decisions register STR-DEC-001 ([docs/06-design-decisions.md](06-design-decisions.md)).

- Regulatory status of an open-vented, fired monotube coil in Amish's home jurisdiction, Texas: the written ruling is asked of the Texas Department of Licensing and Regulation's boiler program. Open prerequisite; gates all further work.
- First co-design partners (decided 2026-10-02): one market garden and one nursery within driving distance of Irving that already steam, solarize or chemically treat soil, found through Texas A&M AgriLife Extension's horticulture contacts. None is named or agreed yet.
- R5 and R4: decided by Amish, 2026-09-25, to study a convective evaporator bank with controlled primary and secondary air and keep the targets. Decided 2026-10-02: size the bank with primary and secondary air dampers so the heated water stays at 8 L or less without relaxing R7, reshape the firebox inside the same study, and plan to restate R4. Done on paper in STR-CAL-001 v0.4: R5 met at about 69 % with the dampers set, R7 met at 7.3 L, R6 met, R11 mass at risk at 499 kg. Proposed, awaiting Amish: restate R4 as 4.5 kg/m² or less with the dampers set.
- What soil permeability and skirt leakage do real beds show, and does the hood need ballast? This decides R1 and R2 and cannot be settled on paper. Decided 2026-10-02: ballast, skirt depth or steam rate are chosen from TRL 4 soil tests that measure leakage at the hood edge, and the hood handles are sized to take ballast weights.
- How much does starting soil moisture change steam demand? Wet soil needs more energy but conducts heat better.

Concept media: [blueprint sheet](../media/concept-blueprint.pdf), [interactive 3D model](../media/viewer.html). General arrangement: [STR-DWG-002](../cad/drawings/STR-DWG-002.pdf).

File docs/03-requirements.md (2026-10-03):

---
doc_id: STR-REQ-001
title: SteamRoot requirements
project: SteamRoot
doc_type: Requirements
version: "0.7"
status: Draft
date: '2026-10-02'
author: Amish Chadha
license: CERN-OHL-S-2.0
revisions:
- version: "0.1"
  date: '2026-09-24'
  author: Amish Chadha
  change: Initial scaffold
- version: "0.2"
  date: '2026-09-24'
  author: Amish Chadha
  change: First measurable requirements for TRL 2, including pressure and safety requirements
- version: "0.3"
  date: '2026-09-25'
  author: Amish Chadha
  change: Apply Amish's 2026-09-25 decisions (two hoods in R2, $1,800 budget in R12); correct the wood heating value in R4; add TRL 3 status from STR-CAL-001
- version: "0.4"
  date: '2026-09-25'
  author: Amish Chadha
  change: Recommendations accepted by Amish (DDR-002)
- version: "0.5"
  date: '2026-10-01'
  author: Amish Chadha
  change: TRL 3 status updated for the constructable design (STR-DDR-003, STR-CAL-001 v0.3); R12 reported against the value-engineering target
- version: "0.6"
  date: '2026-10-02'
  author: Amish Chadha
  change: "R4 to be restated after the evaporator bank study and R5 study to keep R7 (decided 2026-10-02); authority named; no status changed"
- version: "0.7"
  date: '2026-10-02'
  author: Amish Chadha
  change: "Status from STR-CAL-001 v0.4 (evaporator bank, dampers, seal pot overflow, ballast handles): R4 not met to at risk, R5 not met to met, R11 mass met to at risk; R4 restatement to 4.5 kg/m2 proposed, awaiting Amish"
---

# SteamRoot requirements

These requirements were checked by calculation at TRL 3 in STR-CAL-001 v0.4 (`docs/04-calcs/01-sizing.md`), which covers the constructable design of STR-DDR-003 with the evaporator bank, air dampers, seal pot overflow and ballast-rated hood handles decided on 2026-10-02. On 2026-09-25 Amish accepted the recommendations from the TRL 3 review (STR-DDR-002): R2 is restated to the calculated two-hood rate, R6 is split into a header limit and a coil inlet limit, R9 is worded for a standard 15 psi valve sized for the dry-coil refeed flash, R11 applies as towed with the tank drained, R12 is $2,200, and R4 and R5 keep their targets. On 2026-10-01 Amish set the budget as a value-engineering target rather than a limit, so R12 is reported as over or under that target. Of the fifteen checks, none is not met, five are at risk (R4, R2 twice, R11 mass and width), one is not verifiable at TRL 3, eight are met on paper, and R12 is USD 400 over the value-engineering target. R5 is met only while the air dampers hold the excess air near 1.5. Safety requirements (R6, R7, R9 and R10) take priority over performance requirements if they conflict.

> **Safety:** SteamRoot is a fired steam generator. Meeting these requirements on paper does not make it safe or legal to build. A written ruling from the local boiler authority is an open prerequisite for any detail design or build.

*Table 1. Requirements and TRL 3 status.*

| ID | Requirement | Target | Verification (TRL 3 or later) | Status at TRL 3 (STR-CAL-001) |
| --- | --- | --- | --- | --- |
| R1 | Pasteurize soil to working depth | Soil at 70 °C (158 °F) or more for 20 to 30 min at 10 to 15 cm depth across at least 80 % of the hood footprint | Heat balance calculation; later thermocouple probes at 15 cm | Not verifiable at TRL 3 (1D model holds 70 °C at 15 cm if the front reaches 16.5 cm) |
| R2 | Treat beds at a useful rate | About 1.9 m²/h (1.85 m²/h or more) at 15 cm depth; 3.4 m²/h or more at 5 cm depth (weed seed bank only), with two hoods used alternately. Restated from 2 and 5 m²/h until soil tests exist (decided by Amish, 2026-09-25, STR-DDR-002) | Calculation from steam output, steam per m² and hood cycle | At risk (thin margin): 1.88 m²/h at 15 cm, 3.41 m²/h at 5 cm |
| R3 | Generate enough steam | 30 kg/h or more of saturated steam, continuous, from one firebox | Heat transfer and combustion calculation | Met: 30 kg/h at 31.6 kW firing |
| R4 | Limit fuel use | 4 kg or less of wood at 20 % moisture (wet basis; about 14.5 MJ/kg lower heating value) per m² at 15 cm depth. Target kept (decided by Amish, 2026-09-25); to be restated after the evaporator bank study, since even 65 % efficiency leaves it short (decided 2026-10-02) | Energy balance calculation | At risk: 4.2 kg/m² with the dampers set, 4.7 kg/m² with them open (about 72 % efficiency needed for 4 kg/m²). Proposed, awaiting Amish: restate to 4.5 kg/m² or less with the dampers set (STR-CAL-001, section 4) |
| R5 | Use biomass efficiently | 65 % or more of fuel energy delivered as steam, with the economizer. Target kept; a convective evaporator bank with controlled air is under study (decided by Amish, 2026-09-25), to be sized in the next paper iteration with primary and secondary air dampers and without relaxing R7 (decided 2026-10-02) | Energy balance calculation; later flue temperature and fuel weighing | Met on paper: 69 % with the 6.4 m evaporator bank and the dampers holding λ near 1.5; 61 % if the dampers are left open (λ = 2.0) |
| R6 | Stay near atmospheric pressure | Normal working pressure 0.1 bar gauge (1.5 psi) or less at the steam header, where the vent limit applies, and 0.15 bar gauge (2.2 psi) or less at the coil inlet; an open vent to atmosphere that cannot be closed or isolated (redefined by Amish, 2026-09-25) | Pressure drop calculation; design review | Met: header 0.033 bar, coil inlet (now the evaporator bank inlet) 0.128 bar; seal limit 0.084 bar with the overflow; open vent met by design |
| R7 | Keep stored energy low | 8 L or less of water in the heated section; no closed steam drum | Volume calculation from the coil geometry | Met: 7.3 L flooded (coil 5.1 L, bank 0.9 L, economizer 0.6 L, header 0.8 L) |
| R8 | Run between refills | 3 h or more of steaming per feed water fill | Tank volume and steam rate | Met: 4.2 h |
| R9 | Protect against overpressure | A certified steam relief valve set at the lowest standard certified pressure, 15 psi (1.03 bar) or less, with rated capacity for both the full steam output and the dry-coil refeed flash (about 138 kg/h, 13 mm orifice), as a second line of protection behind R6 (reworded by Amish, 2026-09-25) | Valve rating and capacity check | Met on paper: 15 psi set, maker's rating 170 kg/h (375 lb/h) for the 3/4 in valve, 23 % over the flash |
| R10 | Protect the operator and site | Chimney outlet 2.2 m or more above ground with a spark arrestor (mesh 6 mm or finer); fire outdoors only; steam diverted to the vent, not the hood, before the hood is lifted; hood handles 60 °C or cooler | Design review; later surface temperature check | Met: 2.4 m, 6 mm mesh, hood skin 23 °C |
| R11 | Tow with farm vehicles | 500 kg or less as towed, with the feed tank and seal pot drained (filled on site); overall width 1.5 m or less (restated by Amish, 2026-09-25) | Mass estimate from the model and BOM | Mass at risk: 499 kg as towed with both hoods aboard (633 kg full; 437 kg with the hoods on a second vehicle, as decided for the prototype). Width at risk: 1.48 m |
| R12 | Think along a value-engineering lens | Parts cost at or under the USD 2,200 value-engineering target, a hypothetical control target, not a limit (Amish, 2026-10-01; the figure was raised from $1,800 on 2026-09-25, STR-DDR-002, and first from $1,500) | Priced BOM | USD 2,600, USD 400 over the value-engineering target |

## Assumptions

- Soil to 15 cm depth: bulk density 1,300 kg/m³, gravimetric water content 20 % (dry basis), starting temperature 15 °C. At TRL 3 the soil is modeled with a condensation front: soil above the front reaches 100 °C, and the front must reach 16.5 cm so that 15 cm stays at 70 °C or more through a 25-minute hold (STR-CAL-001, section 2). The TRL 2 model heated a uniform layer to 75 °C.
- Specific heat of dry mineral soil 0.84 kJ/(kg K), of water 4.18 kJ/(kg K).
- 70 °C for 30 minutes is widely used as a soil pasteurization target for most weed seeds and fungal pathogens. Some hard-seeded weeds and heat-tolerant viruses need higher temperatures; this is accepted.
- Wood at 20 % moisture (wet basis) has a lower heating value of about 14.5 MJ/kg for a typical hardwood analysis. Earlier versions quoted about 16 MJ/kg, which was too high.
- Pressure thresholds for boiler and pressure vessel rules vary by jurisdiction. R6 and R9 are set to be well below common low-pressure thresholds, but compliance must be confirmed locally. The written ruling from the local boiler authority, the Texas Department of Licensing and Regulation's boiler program (Amish's home jurisdiction is Texas, decided 2026-10-02), is an open prerequisite.
- R11 assumes the machine is towed with the feed tank and seal pot drained and filled from a water supply at the site. Towing full puts it at about 633 kg.
- The R9 capacity check uses the maker's published capacity for the Watts Series 315, 3/4 in, 15 psi valve (375 lb/h); it must be confirmed for the valve actually bought.
- The R2 treatment rate assumes two hoods used alternately, a 25-minute hold, 2 minutes to reset a hood and 1 minute of vented steam each time the hose is moved.

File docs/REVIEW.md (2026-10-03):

# Review note: SteamRoot

## Session 2026-10-02: approved follow-ups carried out

Amish approved on 2026-10-02 that the follow-up actions from the open-decision sign-off be carried out ("APPROVED CHANGES, COMPLETE THESE"), with the render scenes prepared for new photoreal renders. This section records each follow-up of the list below ("Follow-up actions to carry approved decisions into the design").

### Approved follow-ups carried out

1. Decision 1 (obtain the ruling and review the design against it): not done: outreach by Amish; the ruling is not yet obtained.
2. Decision 2 (write to the Texas Department of Licensing and Regulation): not done: outreach by Amish.
3. Decision 4 (size the evaporator bank with dampers, reshape the firebox, propose a restated R4): done. `docs/04-calcs/sizing.py` now runs a forward model of firebox, bank and economizer and a six-option study (STR-CAL-001 v0.4, section 4, Table 4). Chosen: 6.4 m of 15.88 x 1.24 mm 316 tube in two layers, coil cut from 11 to 10 turns, firebox reshaped from 1000 to 960 mm, excess air held near 1.5 by the primary and secondary dampers. Efficiency 68.9 % (61.3 % with dampers open), wood 4.18 kg/m², heated water 7.32 L. R4 restatement proposed (register item 12).
4. Decision 4 (bank and dampers in the model; check R6, R7, R11): done. `cad/src/model.py`: bank box, lining, tube, supports, slot cover, economizer to bank link, rerouted jumper, secondary air slot and slide on the door, longer roof bolts. R6 met (bank inlet 0.128 bar), R7 met (7.3 L), R11 mass at risk (499 kg).
5. Decision 6 (overflow in the model; constructability checks): done. Overflow from a half coupling at the static mark, 350 mm loop seal, trap stay, crossing to the trailer centre line behind the deck and down to 80 mm above the ground; rear clip on the rear rail. Constructability checks: 124 of 124 pass (was 93; 31 added for the new parts and clearances). STEP and STL regenerated, with a new `steamroot-bank` part file.
6. Decision 6 (STR-DWG-116 and STR-DWG-002): done. STR-DWG-116 Rev P2; STR-DWG-002 Rev P4; new sketch STR-DWG-125 for the overflow.
7. Decision 6 (seal pot section 3.17, step 15, joint 7, S4): done in STR-BLD-001 v0.3; joint 7 redrawn as a front cut through the pot and overflow.
8. Decision 6 (overflow in the BOM, priced): done. BOM line 9 USD 150 to USD 220 (pipe, elbows, half coupling, plug, stay and clip; typical hardware store prices, not checked live).
9. Decision 6 (overflow check in STR-CAL-001): done, section 5. With the overflow the annulus cannot rise, so the seal blows at the 890 mm dip leg depth: 0.084 bar, under the 0.094 bar limit whatever the fill; the 110 mm rise is removed. A loop seal (3.29 kPa) was needed because the refeed flash raises the pot head space by about 2.35 kPa and would otherwise blow steam out at ground level.
10. Decision 8 (draining and ice check in the operator instructions): not done: the operator instructions are not yet written (TRL 4 work); the rule is in safety stops S4 and S10 of the build plan, now including the loop seal plug.
11. Decision 10 (product model; renders, card and social preview on Amish's Mac): product model done; renders not done here. `cad/src/product_model.py` now takes the firebox on skids, coil, bank box, economizer and chimney heights, header post, pot on its foot plate, overflow, diverter position, discharge and vent line, dampers, feed lines and handles from `model.py`. Render scenes exported to `/home/claude/renders/steamroot` (hero, exploded, detail; one .npz and .json each plus `steamroot__jobs.json`). `media/render-*.png`, `media/card.png` and `media/social-preview.png` are to be rendered on Amish's Mac.
12. Decision 11 (handles sized for ballast; ballast load in the hood section): done. Handles 30 x 30 x 2.5 steel tube on standoffs and 100 x 100 x 3 foot plates through-bolted to backing plates; 40 kg a hood at a load factor of 2 gives about 34 MPa (factor 7 on yield). Noted in STR-BLD-001 sections 3.20 and 3.29; new sketch STR-DWG-126.
13. Decision 11 (skirt leakage in the TRL 4 soil test plan): not done: TRL 4 work, on hold.

### Requirement status changes (STR-CAL-001 v0.4)

- R4: not met (5.6 kg/m²) to at risk (4.2 kg/m² with the dampers set).
- R5: not met (51 %) to met on paper (69 %), only while the dampers hold λ near 1.5.
- R11 mass: met (468 kg) to at risk (499 kg towed with the hoods; 437 kg without).
- Unchanged in kind: R6 met (header 0.033 bar, bank inlet 0.128 bar, seal 0.084 bar), R7 met (6.9 L to 7.3 L), R9 met (flash 155 to 138 kg/h, margin 10 % to 23 %), R2 and R11 width at risk, R1 not verifiable.
- Cost: Value-engineering target: USD 2,200. Estimated cost of the constructable design: USD 2,600 (USD 400 over the target). Mass 633 kg full, 499 kg towed drained.

### Documents changed and new versions

- `cad/src/model.py` (bank, dampers, overflow, handles, 124 checks); `cad/step/`, `cad/stl/` regenerated
- `docs/04-calcs/sizing.py`; `docs/04-calcs/01-sizing.md` STR-CAL-001 v0.4
- `bom/bom.csv` (lines 1, 5, 6, 9, 12, 19, 21 revised; line 22 added); `bom/bom-notes.md`
- `docs/03-requirements.md` STR-REQ-001 v0.7; `docs/02-concept.md` STR-PRC-001 v0.7; `docs/05-build-plan.md` STR-BLD-001 v0.3; `docs/06-design-decisions.md` STR-DEC-001 v0.3; `docs/decisions/0002-recommendations-accepted.md` STR-DDR-002 v0.3; `docs/decisions/0003-design-for-construction.md` STR-DDR-003 v0.3; `README.md`
- Drawings: STR-DWG-002 Rev P4; STR-DWG-101, 104, 106, 107, 108, 110, 111, 116, 119 Rev P2; new STR-DWG-122 to 126; insets of 109, 112, 113, 120 and 121 regenerated
- Pictures: overview, joints 1 to 10 (5, 7 and 9 changed), steps 1 to 20 (6, 10, 11, 15, 18 and 19 changed); concept media (hero, cutaway, exploded, flow, blueprint, `model.glb`). `cad/src/concept_media.py` now cuts the cutaway solid by solid (the coil compound needed about 5 GB in one boolean).
- `cad/src/product_model.py`, `cad/src/sheets.py`, `cad/src/build_plan_media.py`

### Proposed, awaiting Amish

- Register item 12: restate R4 as 4.5 kg/m² or less at 15 cm with the dampers set (options 4.5, 5.0 or keep 4).
- Register item 13: count R11 without the hoods, which ride on a second vehicle (437 kg), or save mass elsewhere.
- The overflow's 350 mm loop seal is a detail the 2026-10-02 decision did not name; it keeps the decided overflow from venting steam at ground level during a refeed flash. It changes the safety case slightly and should be confirmed by Amish and put to the authority with the rest.
- Appearance deviations in `product_model.py`: the cast grate is drawn as a bar grid sized to the lining rather than the 300 mm grate, and the door carries a ceramic glass window the made door does not have.

### Safety notes

- R5 now depends on the operator holding the dampers near λ = 1.5; less excess air also raises carbon monoxide, so the CO alarm rule stands.
- Each start pushes about 0.3 L of seal water out of the overflow; the pot must be topped up to the mark before every start (S4) or the seal is shallower than drawn (safe direction, but the vent then opens earlier).
- The overflow loop seal must be kept full and drained in frost (S4, S10).

### Cross-repo actions

None.

## Session 2026-10-02: open decisions decided by Amish

Amish wrote on 2026-10-02: "i approve your recommendations for all 555 open decisions." Every open decision in this repo's register was decided as recommended and moved to "Decisions made" in `docs/06-design-decisions.md`, dated 2026-10-02.

### Decisions recorded

11 decisions recorded (register items 1 to 11). The register's "Open decisions" section now reads: "None. All open decisions were decided on 2026-10-02."

### Documents changed

- `docs/06-design-decisions.md` v0.2
- `docs/decisions/0003-design-for-construction.md` v0.2
- `docs/decisions/0001-trl2-review-decisions.md` v0.3
- `docs/decisions/0002-recommendations-accepted.md` v0.2
- `docs/03-requirements.md` v0.6
- `docs/02-concept.md` v0.6
- `docs/01-problem.md` v0.5
- `docs/05-build-plan.md` v0.2
- `README.md` (DDR-003 status; not a controlled document)

PDFs re-rendered with `python3 .kit/render.py`. The CAD model, BOM quantities and prices, and pictures were not changed.

### Follow-up actions to carry approved decisions into the design

1. Decision 1 (documents): Obtain the written ruling (see decision 2) and review the design against it before any purchase or build; record any stricter requirement it sets as a new decision.
2. Decision 2 (documents): Write to the Texas Department of Licensing and Regulation's boiler program for the ruling on an open-vented, fired monotube coil, with the design precis and drawing attached.
3. Decision 4 (calculations): In the next paper iteration, size the evaporator bank with primary and secondary air dampers in `docs/04-calcs/sizing.py` so the heated water stays at 8 L or less (smaller-bore bank tube or fewer firebox turns), reshape the firebox in the same study, and propose a restated R4.
4. Decision 4 (model): Add the evaporator bank and air dampers to `cad/src/model.py` once sized, and check R6, R7 and R11.
5. Decision 6 (model): Add the seal pot overflow branch at the static water mark and its pipe down to ground level at the back of the trailer, away from the operator's side, to `cad/src/model.py`, and rerun the constructability checks.
6. Decision 6 (drawings): Regenerate the water-seal pot making sketch (STR-DWG-116) and STR-DWG-002 with the overflow branch and pipe.
7. Decision 6 (build plan pictures and renders): Add the overflow to the seal pot section 3.17, step 15 and joint 7 pictures of STR-BLD-001, and to the S4 check.
8. Decision 6 (BOM): Add the overflow branch, pipe and clips to the header and water-seal BOM line and price them.
9. Decision 6 (calculations): Check in STR-CAL-001 that the overflow sets the seal depth so the pot cannot exceed the 0.094 bar limit, including the 110 mm rise outside the dip leg.
10. Decision 8 (documents): Add the seal pot draining and ice check to the operator instructions when they are written.
11. Decision 10 (build plan pictures and renders): Update `cad/src/product_model.py` to the constructable design (1000 mm firebox with the coil above the fire, skids, header at 1.55 m on a post, seal pot on the deck) and regenerate `media/render-*.png`, `media/card.png` and `media/social-preview.png` on Amish's Mac.
12. Decision 11 (model): Size the hood handles and their standoffs in `cad/src/model.py` to carry ballast weights, and note the ballast load in the hood section of STR-BLD-001.
13. Decision 11 (documents): When TRL 4 is opened, include skirt leakage measured at the hood edge in the soil test plan.

### Points found in the review

- R4 (4 kg wood per m²) needs about 72 % efficiency (STR-CAL-001 section 4), so the evaporator bank study aimed at R5's 65 % cannot close R4; the register treats them as closing together.
- The evaporator bank length moved from about 3.3 m (STR-DDR-002, item 1) to about 4.3 m (STR-CAL-001 v0.3) after the taller firebox; STR-DDR-002 still quotes the old figure.
- The seal pot overflow (item 6) and the freezing rule (item 8) both protect the water seal, which is the pressure limit for the whole machine; they should be read together as one safety question rather than as an option and an operating rule.
- Item 10 is listed last although every other build item depends on it; it should sit first in the register as in the other repos.

TRL 4 remains on hold by Amish's instruction.

## Session 2026-09-24: /populate to a strong TRL 2

### What was done

- `docs/01-problem.md` (STR-PRB-001 v0.2): problem, users and context, constraints, out of scope, prior work on steam soil disinfestation (described without links), safety note.
- `docs/03-requirements.md` (STR-REQ-001 v0.2): 12 measurable requirements (R1 to R12) with targets, planned verification and stated assumptions.
- `docs/02-concept.md` (STR-PRC-001 v0.2): how it works, 15 main components numbered to match the exploded view and BOM, first-order energy and pressure numbers with assumptions, design choices, a full safety section, open questions.
- `cad/src/concept_media.py`: massing model (trailer, wheels, feed tank, feed pump, firebox, coil, economizer, chimney, header and vent standpipe, relief valve, hose, hood) with the 1.75 m person for scale.
- `media/`: hero, blueprint sheet STR-DWG-001 (PNG and PDF), cutaway, exploded view with BOM callouts, energy flow diagram (values marked as estimates), `model.glb` and `viewer.html`.
- `bom/bom.csv`: 15 lines with indicative prices, items 1 to 12 numbered to match the exploded view; `bom/bom-notes.md`.
- `README.md`: hero image and links line.
- `docs/pdf/`: branded PDFs of the three controlled documents.

### Key results (estimates, to be checked at TRL 3)

| Quantity | Estimate | Requirement |
| --- | --- | --- |
| Heat to pasteurize soil to 15 cm | about 19.6 MJ/m² | |
| Steam needed at 15 cm | about 14 kg/m² (60 % hood transfer efficiency) | |
| Steam output | 30 kg/h (design point) | R3 met by design |
| Fuel to steam efficiency | about 62 % with economizer, 55 % without | R5 (65 %) **not met** |
| Wood use | about 7.9 kg/h, about 3.6 kg/m² at 15 cm | R4 met, thin margin |
| Treatment rate | about 2.2 m²/h at 15 cm, 6.5 m²/h at 5 cm (steam limited) | R2 met only with two hoods; about 1.2 m²/h with one |
| Steam-side pressure | about 0.05 bar coil drop, vent limit about 0.1 bar gauge | R6 met by design |
| Water in heated section | under 6 L | R7 met |
| Loaded mass | about 490 kg | R11 met, thin margin |
| Parts cost | about $1,500 | R12 met, no contingency |

Requirements not met or at risk:

- **R5 not met.** The economizer can only put about 2.4 kW into 30 kg/h of feed water before it nears boiling, so it lifts efficiency from about 55 % to about 62 %. Closing the gap needs a better firebox and coil or a combustion air preheater.
- **R2 at risk.** A single hood spends 25 minutes of each cycle holding temperature, which cuts the real rate to about 1.2 m²/h. Two hoods used alternately are needed to reach 2 m²/h.
- **R1 unverified.** Every rate and fuel figure depends on the assumed 60 % hood transfer efficiency.
- A 12.7 mm coil, as first imagined, would need more than 2 bar at its inlet. The concept now uses a 25.4 mm coil to stay near atmospheric pressure.

### Proposed, awaiting Amish

1. Open-vented architecture: water-seal vent standpipe as the primary pressure limit, certified relief valve as the second line, no isolating valve anywhere on the steam side.
2. Monotube coil in 25.4 mm 316 stainless (alternatives: parallel 12.7 mm circuits; soft copper, about $100 cheaper but weak if run dry).
3. Hood steaming with two hoods used alternately (alternatives: one hood plus an insulating blanket; accept about 1.2 m²/h).
4. Feed control: fixed pump rate with a coil outlet temperature alarm (alternative: thermostat-controlled pump speed).
5. Budget: parts use the full $1,500 with no contingency. Options: (a) raise `budget_usd` to $1,800 to allow 20 % contingency; (b) keep $1,500 and accept the risk; (c) cut scope, for example a sheet instead of a hood. Recommended: (a). `project.yaml` is unchanged.
6. First users: one market garden and one nursery; first jurisdiction for the regulatory check: Amish's home jurisdiction.

### Safety concerns

- This is the riskiest concept in the portfolio. The documents carry safety blockquotes for sealing, relief valve, local boiler rules, steam burns, dry coil, fire, carbon monoxide and hot surfaces, and must keep them.
- **Regulatory status is the gating risk.** Whether an open-vented, fired coil is exempt from boiler and pressure vessel rules is unconfirmed and differs by jurisdiction. Recommend a written ruling from the local boiler authority before any TRL 3 detail work.
- **Dry-coil restart** is the most likely serious failure: a biomass fire cannot be switched off, so a pump or tank failure overheats the coil, and refeeding it can flash violently.
- **Carbon monoxide** in greenhouses: steam may go into a greenhouse, but the generator must never do so.
- **Fire** from sparks in dry fields: spark arrestor, cleared ground and burn-ban compliance are required.

### Recommended next step

Review this note and the media. Decide on items 1, 2 and 5 above. If approved, confirm regulatory status first, then run `/advance-trl3` to check the efficiency, two-phase pressure drop and hood heat transfer by calculation.

## Session 2026-09-25: TRL 3

Authority: on 2026-09-25 Amish wrote "proceed with all of your recommendations across all batches. Make sure we don't proceed to TRL 4 on any of them." The TRL 2 recommendations above are recorded as decided in STR-DDR-001, and the repo now claims TRL 3 (`trl: 3`, `trl_target: 3`). TRL 4 is on hold by Amish's instruction.

**Regulatory prerequisite, still open.** The approved recommendation included getting a written ruling from the local boiler authority before TRL 3 detail work. That ruling cannot be obtained in a documentation session, and it has not been obtained. This session therefore did only paper calculations, a massing-plus model and a preliminary drawing. The ruling is marked as an open prerequisite in STR-DDR-001, STR-PRB-001, STR-PRC-001, STR-REQ-001, STR-CAL-001, in the notes and title block of drawing STR-DWG-002, and in `bom/bom-notes.md`. No detail design, purchase or build should happen before it.

### What was done

- `docs/decisions/0001-trl2-review-decisions.md` (STR-DDR-001 v0.1): the six decided items and the five items still open.
- `docs/04-calcs/01-sizing.md` (STR-CAL-001 v0.1) and `docs/04-calcs/sizing.py`: first-principles sizing (soil heat with a condensation-front model, hood cycle, combustion and firebox heat transfer, economizer, two-phase pressure drop, stored water, dry-coil refeed, relief valve sizing, mass and cost) with a results table for every requirement. The script reads geometry from the model and prices from the BOM and prints every number the note quotes.
- `cad/src/model.py`: parametric build123d model (helical coil, fiber-lined firebox, economizer, chimney, header with a 1 m water-seal pot and vent, relief valve, hose, two hoods with skirts, trailer). Exports `cad/step/steamroot.step` and `cad/stl/steamroot.stl` plus firebox, coil, header and hood parts.
- `cad/src/sheets.py` and `cad/drawings/STR-DWG-002.svg`, `.pdf`, `.png`: general arrangement at Rev P1 (STR-DWG-001 is the concept blueprint in `media/`).
- `bom/bom.csv`: 16 lines, all priced with a supplier or supplier type; second hood and feed and coil alarms added; `bom/bom-notes.md` updated.
- `cad/src/concept_media.py`: now builds the media from `model.py` and quotes CAL-001; all media refreshed.
- `docs/01-problem.md`, `docs/02-concept.md`, `docs/03-requirements.md` bumped to v0.3 with the decisions and TRL 3 results; `project.yaml` (TRL 3, budget $1,800, evidence list); `README.md` (TRL badge, status line, key components).

### Requirement status (STR-CAL-001), not met first

| ID | Result | Target | Status |
| --- | --- | --- | --- |
| R2 | 1.88 m²/h at 15 cm; 3.41 m²/h at 5 cm (two hoods) | 2 and 5 m²/h | Not met |
| R4 | 5.4 kg wood per m² at 15 cm | 4 kg/m² | Not met |
| R5 | 53.5 % fuel to steam | 65 % | Not met |
| R6 | 0.110 bar gauge at the coil inlet (header 0.033 bar) | 0.1 bar | Not met (10 % over); open vent met |
| R11 | 536 kg loaded with a full tank | 500 kg | Not met |
| R12 | $1,915 parts | $1,800 | Not met |
| R9 | Standard certified valve is 15 psi = 1.03 bar; 6.2 mm orifice needed | 1 bar (15 psi) or less | At risk |
| R11 | 1.48 m width | 1.5 m | At risk |
| R1 | Holds 70 °C at 15 cm in the 1D model if the front reaches 16.5 cm | 70 °C, 20 to 30 min | Not verifiable at TRL 3 |
| R3, R7, R8, R10 | 30 kg/h at 40.7 kW; 7.0 L; 4.2 h; 2.4 m chimney, 23 °C hood skin | | Met |

Counts: 7 not met, 2 at risk, 1 not verifiable at TRL 3, 4 met (14 checks on 12 requirements).

Numbers from the TRL 2 note that changed: efficiency 62 % became 53.5 %; wood use 7.9 kg/h became 10.1 kg/h because the wood heating value at 20 % moisture is 14.5 MJ/kg, not 16; steam per m² at 15 cm 14 became 15.6 kg/m² (soil behind the steam front sits at 100 °C); rate at 5 cm 6.5 became 3.41 m²/h (hold limited); loaded mass 490 became 536 kg (second hood, seal pot, heavier trailer assumption); coil pressure drop 0.05 became 0.077 bar (two-phase and curvature effects); parts cost $1,500 became $1,915.

### Decisions recorded

Decided by Amish, 2026-09-25, going with the recommendation (STR-DDR-001): open-vented architecture with water-seal vent and certified relief valve; 25.4 mm 316 stainless monotube coil; two hoods used alternately; fixed-rate feed with coil outlet and tank level alarms; `budget_usd` raised to $1,800; first users one market garden and one nursery, first jurisdiction Amish's home jurisdiction.

### Items still awaiting Amish

1. **Regulatory ruling** from the local boiler authority: approved, not obtained. Open prerequisite.
2. Which jurisdiction is "home" and which authority to ask.
3. The named market garden and nursery (no partner is named).
4. Wood only, no liquid fuel backup (from STR-PRC-001; not in the TRL 2 review list). **Decided by Amish, 2026-09-25: go with recommendation** (STR-DDR-002).
5. How to close R5 and R4: options are (a) a convective evaporator bank in the flue before the economizer, (b) controlled primary and secondary air to reach λ near 1.5, (c) a combustion air preheater (about 62 % alone), or (d) relax R5 to about 55 % and R4 to about 5.5 kg/m². Recommendation: study (a) with (b) at the next paper step, and keep the targets for now. **Decided by Amish, 2026-09-25: go with recommendation** (STR-DDR-002).
6. How to treat R2: (a) accept 1.9 m²/h at 15 cm and restate the 5 cm target at about 3.4 m²/h; (b) a third hood (helps 5 cm only, to 4.43 m²/h); (c) raise steam output, which needs a bigger firebox. Recommendation: (a) until soil tests exist. **Decided by Amish, 2026-09-25: go with recommendation** (STR-DDR-002).
7. R6: accept 0.11 bar at the coil inlet (the header is at 0.03 bar) or reduce coil drop with a shorter coil or larger tube. Recommendation: redefine R6 as 0.1 bar at the header and 0.15 bar at the coil inlet, because the vent limit applies at the header. **Decided by Amish, 2026-09-25: go with recommendation** (STR-DDR-002).
8. R9 wording: change "1 bar (15 psi) or less" to "15 psi (1.03 bar) or less", the lowest standard certified set pressure. Also size the valve for the dry-coil refeed flash (about 14 mm orifice), not only for 30 kg/h. Recommendation: both. **Decided by Amish, 2026-09-25: go with recommendation** (STR-DDR-002).
9. R11 mass: (a) tow with the tank and seal pot drained (402 kg) and fill on site; (b) a 100 L tank (3.3 h per fill); (c) raise the limit to 550 kg. Recommendation: (a), written into the requirement as "500 kg or less as towed, with the tank drained". **Decided by Amish, 2026-09-25: go with recommendation** (STR-DDR-002).
10. R12 cost: $1,915 is $115 over the new $1,800 budget with no contingency. Options: (a) raise the budget to about $2,200 for 15 % contingency; (b) keep $1,800 and cut, for example one hood; (c) accept. Recommendation: (a). `budget_usd` stays at 1800. **Decided by Amish, 2026-09-25: go with recommendation** (STR-DDR-002).
11. Design details raised at TRL 3: fiber lining instead of castable (recommended, for mass); one hose moved between hoods with a steam-rated coupling instead of two hoses (recommended, for cost). **Decided by Amish, 2026-09-25: go with recommendation** (STR-DDR-002).

### Safety concerns

- **Regulatory status** is still the gating risk (see above).
- **Dry-coil refeed.** A dry coil near 520 °C can flash about 1.3 kg of water; if that happens over 30 s it is about 155 kg/h, five times the design flow. The vent and relief valve are sized for 30 kg/h. The coil outlet alarm and the rule never to refeed a hot, dry coil remain essential.
- **Steam jets at the hood skirt.** In soils finer than sand the pressure needed to push steam through the treated layer (about 2,400 Pa in a sandy loam) is ten times what the 29 kg hood can hold down (235 Pa), so steam will escape under the skirt. This is a burn hazard at foot level.
- **Hose changeover.** Two hoods mean the hot hose coupling is moved about twice an hour. Steam must be diverted to the vent first.
- **Hot surfaces and fire.** Firebox skin about 100 °C, flue gas about 450 °C at the spark arrestor.
- **Carbon monoxide** in greenhouses and **fire** in dry fields, as in the TRL 2 note.

### Other notes

- No TRL 4 material exists in the repo; none was created. `firmware/` and `electronics/` hold only placeholders.
- Citations: the TRL 2 documents describe prior work without sources, and there is no list of unchecked citations. No sources were added. The only web check made was the relief valve price (SupplyHouse.com listing for Watts 315M2-015, $68.19, 2026-09-25). Prior-work sources are still to be cited.
- The media render takes about eight minutes because of the helical coil in the hidden-line projection. `media/model.glb` is re-exported at a coarser tessellation to keep it small.

### Recommended next step

Obtain the written ruling from the local boiler authority, and have Amish decide items 5 to 11 above. After that, a second paper iteration at TRL 3 (a revised coil and flue layout to address R5 and R4, and restated R2, R6, R9 and R11) is the right next step. **TRL 4 is on hold by Amish's instruction.** For the record only, TRL 4 would need: the regulatory ruling in hand; a lab test article of the coil, header and water seal; a test plan and report (TST, `environment: lab`) for steam output, efficiency, pressure at the coil inlet and header, dry-coil alarm response and relief valve capacity; soil permeability and skirt leakage tests with the hood; and build log entries. None of this has been started.

## Session 2026-09-25: recommendations accepted

Authority: on 2026-09-25 Amish wrote "i accept all your recommendations, go with them across all repos." Every open item with a recommendation is now **Decided by Amish, 2026-09-25: go with recommendation**, recorded in STR-DDR-002 (`docs/decisions/0002-recommendations-accepted.md`). Items without a recommendation stay open.

### Decisions applied and what changed

| Item | Decision | Before | After |
| --- | --- | --- | --- |
| R12 budget | Raise to about $2,200 for 15 % contingency | `budget_usd` 1800; $1,915 BOM, $115 over | `budget_usd` 2200; $285 contingency; met |
| R2 rate | Accept the two-hood rate until soil tests exist | Targets 2 and 5 m²/h; not met | Targets 1.85 (about 1.9) and 3.4 m²/h; 1.88 and 3.41 m²/h; at risk |
| R6 pressure | 0.1 bar at the header, 0.15 bar at the coil inlet | 0.110 bar against 0.1 at the inlet; not met | Header 0.033, inlet 0.110 bar; met |
| R9 relief valve | Word as 15 psi (1.03 bar) or less; size for the refeed flash | At risk; capacity unconfirmed | Watts Series 315, 3/4 in, 375 lb/h (170 kg/h) against a 155 kg/h flash; met on paper; valve unchanged |
| R11 mass | 500 kg or less as towed, tank drained | 536 kg full; not met | 402 kg as towed; met (width 1.48 m still at risk) |
| R5 and R4 | Keep targets; study an evaporator bank with controlled air | No study | CAL-001 section 4: about 3.3 m of 25.4 mm tube reaches 65 % at λ = 2.0; R4 needs about 72 %; both still not met |
| Firebox lining | Ceramic fiber | Proposed | Decided; no geometry change |
| Hose | One hose moved between hoods | Proposed | Decided; no BOM change |
| Fuel | Wood only | Proposed | Decided |

Files changed: `project.yaml` (budget), `README.md` (budget, status line, new write-up sections), STR-PRB-001 v0.4, STR-PRC-001 v0.4, STR-REQ-001 v0.4, STR-CAL-001 v0.2 and `sizing.py`, STR-DDR-001 v0.2, new STR-DDR-002 v0.1, `bom/bom.csv` and `bom/bom-notes.md` (notes only; total unchanged at $1,915), drawing STR-DWG-002 Rev P1 to P2 (notes only; geometry unchanged), concept media key figures (towed mass). All PDFs, drawings and media were regenerated.

### Requirement status (STR-CAL-001 v0.2), not met first

| ID | Result | Target | Status |
| --- | --- | --- | --- |
| R4 | 5.4 kg/m² at 15 cm | 4 kg/m² | Not met |
| R5 | 53.5 % | 65 % | Not met |
| R2 | 1.88 m²/h at 15 cm; 3.41 m²/h at 5 cm | 1.85 and 3.4 m²/h | At risk (thin margin) |
| R11 | 1.48 m width | 1.5 m | At risk |
| R1 | Holds 70 °C at 15 cm in the 1D model if the front reaches 16.5 cm | 70 °C, 20 to 30 min | Not verifiable at TRL 3 |
| R3, R6, R7, R8, R9, R10, R11 mass, R12 | 30 kg/h; header 0.033 and inlet 0.110 bar; 7.0 L; 4.2 h; 170 kg/h valve; 2.4 m chimney; 402 kg towed; $1,915 | | Met |

Counts: 2 not met, 3 at risk, 1 not verifiable at TRL 3, 9 met (15 checks on 12 requirements). Before: 7 not met, 2 at risk, 1 not verifiable, 4 met.

### Items still awaiting Amish

1. Written ruling from the local boiler authority: approved, not obtained. Open prerequisite for any detail design or build.
2. Which jurisdiction is "home" and which authority to ask (no recommendation).
3. The named market garden and nursery (no recommendation).

### Cross-repo actions

None. No SteamRoot decision needs a change in another repo.

### Notes

- The evaporator bank is not yet in the model. About 4 m of bank tube would add about 1.5 L of water and take the heated section to about 8.5 L, over R7's 8 L, so the next paper iteration must resolve R7 together with R5, R6 and R11.
- `README.md` now has the Concept rationale, Burning platform, Where it could be used and What sparked the idea sections, with cited figures (Oerke 2006, FiBL 2025, the US 2016 critical use exemption rule, UNEP 2014).
- **TRL 4 remains on hold** by Amish's instruction. Decided items that need TRL 4 work (measured efficiency, soil permeability and skirt tests for R1 and R2, capacity check of the valve actually bought) are recorded as decided but on hold. Nothing was built, bought or tested.

## Session 2026-09-26: product appearance model and photoreal renders

Amish chose this repo for the first batch of product renders on 2026-09-26. This session added an appearance model for photoreal renders. It changes no design figure, requirement, BOM line or calculation.

### What was done

- New `cad/src/product_model.py`: `product_parts()` returns 104 named parts (75 shell, 8 internal, 18 accessory, 3 context), each with colour, material, BOM line, group and exploded offset. It also defines `TITLE` and `RENDER_VIEWS` (hero, exploded and a detail view of the generator on its trailer without the person, the ground or the hoods). Every shape is valid and tessellates at the export tolerance.
- `README.md`: the hero image now points to `media/render-hero.png`, and the links line starts with the exploded render. The render files are produced separately by the portfolio render pipeline.

### What the appearance model adds

- Filleted firebox, economizer, drum, hood and enclosure edges; angle-iron bands at the firebox top and bottom and a base flange under the economizer, read as seams.
- Firebox door with a ceramic glass window onto a glowing fire bed, a wood charge and the coil; hinges, latch with a hardwood grip, and a slotted air damper plate with a knob.
- Economizer access panel with eight bolts, a raised STEAMROOT mark, condensate drain valve with a lever, and an internal tube bank for the exploded view.
- Stainless chimney with a base collar and joint band, spark arrestor cage with a 6 mm mesh screen, and a conical rain cap.
- Teal water-seal pot with deck flange and level sight tube, DN50 header with end flange, vent pipe with an open top cap, diverter valve with lever and steam quick coupling, bronze relief valve with test lever and set-pressure tag, and a 0 to 1 bar gauge on a siphon.
- Labels as thin raised parts: "HOT SURFACE / DO NOT TOUCH" on the firebox, "OPEN VENT / 0.1 BAR MAX / NEVER PLUG" on the seal pot, and "HOT STEAM" on each hood.
- Feed drum with rolling hoops, filler cap, level sight tube and two fabric ratchet straps on a saddle cradle; pump and alarm enclosure with a lid, screws, a lit running indicator, an alarm indicator and a buzzer grille.
- Trailer detail: perimeter frame with crossmembers and stake pockets, deck plate, leaf springs and hangers, coupling head and lever, jockey wheel jack, teal mudguards, tail lights and side reflectors, treaded tyres, and rims with hubs and wheel nuts.
- Aluminum steam hoods with stiffening beads, round handles on standoffs, galvanized skirts, inlet couplings and teal accent bands.
- Context: a gravel pad under the trailer, a soil bed under the hoods, and the shared clay mannequin (1.75 m, standing pose) at the firebox, facing the door.

### Differences from model.py (Proposed, awaiting Amish)

All main dimensions and interfaces come from `PARAMS` in `model.py`, and the coil geometry is used unchanged. These appearance choices differ from the massing model:

1. **Door opening in the firebox.** The massing shell is a closed box behind the door. The appearance model cuts a 300 x 240 mm opening in the shell and lining behind the door so the window shows the fire. Recommendation: add the opening to `model.py` at the next model revision, since a real firebox needs it.
2. **Header support mast and stay.** `model.py` shows the header carried only by the coil outlet pipe. The appearance model adds a 50 mm square mast from the deck to the header underside and a stay to the seal pot. Recommendation: accept as a placeholder and size the support at detail design.
3. **Economizer to coil jumper.** The coil inlet in `model.py` ends beside the economizer box. The appearance model adds a short jumper into the economizer +X face. Recommendation: add it to `model.py`.
4. **Feed lines.** Drum to pump and pump to economizer lines are drawn as indicative 16 mm hoses; `model.py` has none. Recommendation: accept as indicative routing.
5. **Steam hose routing.** The hose starts and ends at the `model.py` points (diverter coupling and first hood inlet) but runs as a smooth drooping curve instead of the square polyline. Recommendation: accept; `model.py` already calls the routing indicative.
6. **Items drawn that the BOM lists as not drawn.** The pressure gauge (item 14) and the alarm indicators and buzzer (item 16) are shown on the header and the pump enclosure. The battery (item 13) is still not drawn. Recommendation: accept; no BOM change.
7. **Appearance additions with no BOM line of their own.** Mudguards, tail lights, reflectors, leaf springs and the jockey wheel are shown as part of the used trailer (item 1); drum straps are shown with the drum (item 3). Recommendation: accept; they come with a used trailer or cost a few dollars.
8. **Air damper height.** The damper plate sits about 15 mm lower than the `model.py` box so it clears the door. Recommendation: accept.
9. **Hoods and hose in the accessory group.** This keeps them out of the detail view so the generator can fill the frame; they still appear in the hero and exploded views.

### Status

This is an appearance model only: no tolerances, no fabrication detail, labelled CONCEPT, NOT FOR FABRICATION. `trl` stays 3 in `project.yaml`, and TRL 4 remains on hold by Amish's instruction. The written ruling from the local boiler authority is still an open prerequisite for any detail design or build.

### Safety

The renders show hot surfaces and a pressure-limiting vent. The labels in the model repeat the Safety section: the water seal and vent must never be plugged or valved off, and the firebox, flue, header and hoods are burn hazards in use.

## Session 2026-09-27: kit 1.5.0 and image quality

- Kit 1.5.0 synced: STANDARDS v1.5 (sections 12 to 15: product renders, storefront images and image quality, public release, authorship and signing), `.kit/cards.py`, `.kit/image_qc.py`, `.kit/release_gate.py`, issue templates, and the `/render-product` and `/release` commands. `CLAUDE.md` now matches `.kit/CLAUDE.md`.
- Every `media/render-*.png` recaptioned from its original render with the new layout: the title, concept label and repository sit in a band above the render and the view note in a band below it, each line wrapped to the image width, so no text overlaps other text or the render or runs off the image. `media/card.png` and `media/social-preview.png` regenerated with the same rules.
- `python .kit/image_qc.py` and `python .kit/release_gate.py` pass. trl stays 3.

## Session 2026-10-01: kit 1.7.0, constructable design and prototype build plan

Authority: Amish approved the build plan format on 2026-09-30 and asked for it across all repos, with outstanding decisions kept in a separate design decisions register; on 2026-09-30 he wrote "If you are realising that the design cannot be built as per concept - fix the design assumptions to match and be physically feasible as you draw the illustrations"; on 2026-10-01 he set budgets as value-engineering targets. TRL stays 3; nothing was built, bought or tested.

### What was done

- Kit 1.7.0 installed (`.kit/`, `.claude/commands/`); `CLAUDE.md` matches `.kit/CLAUDE.md`.
- `cad/src/model.py` rewritten as a constructable model: every component keyed and modelled as made or bought, with fixings, and 93 build123d constructability checks (`python cad/src/model.py --check`), all passing, including the order in which the coil goes into the firebox. `--mass` prints the parts added for construction.
- `docs/decisions/0003-design-for-construction.md` (STR-DDR-003 v0.1, Draft): every design change with its reason, made under Amish's 2026-09-30 instruction to make the design physically buildable; open for his review.
- `docs/05-build-plan.md` (STR-BLD-001 v0.1): the illustrated build plan. `cad/src/build_plan_media.py` draws the overview, 21 making sketches (`cad/drawings/STR-DWG-101` to `121`), 10 joint close-ups, 20 step pictures and the 12 V wiring diagram (`docs/05-build-plan/`).
- `docs/06-design-decisions.md` (STR-DEC-001 v0.1): 11 open decisions, 8 items to confirm when parts are bought, the value engineering section and the decisions made.
- `bom/bom.csv`: lines 5, 6 and 8 respecified, lines 17 to 21 added; `docs/04-calcs/sizing.py` and STR-CAL-001 v0.3 rerun for the new geometry; STR-REQ-001 v0.5 and STR-PRC-001 v0.5 updated; STR-DWG-002 Rev P3; STEP, STL and concept media regenerated; `project.yaml` (`design_state: constructable`, new evidence); `README.md` (links, "Building the prototype").

### Design changes made for construction (STR-DDR-003)

1. C1 Firebox 1000 mm tall (was 650 mm) with the coil above the fire: door opening 300 x 240 mm, grate on a stand with an ash pit, air inlet and slide damper below the coil; 280 mm of fire space.
2. C2 Three stainless coil brackets welded to the shell through the lining.
3. C3 Bolted roof on an angle frame; the coil goes in from the top and its tails slide out through wall slots closed by gland plates with rope packing; unions outside; separate outlet pipe; the inlet jumper rerouted so nothing crosses.
4. C4 Economizer as a bolted box on studs with a serpentine tube bank (7.3 m, bent on a standard 38 mm radius) on support bars, a bolted lid carrying the chimney spigot, and bulkhead unions.
5. C5 Firebox skids welded under the firebox and bolted into the trailer side rails, with a 50 mm air gap.
6. C6 Seal pot on a foot plate; dip leg 890 mm below the static mark so the seal still blows at 1.0 m of water (0.094 bar); pot top raised; header lowered to 1550 mm.
7. C7 Header post with saddle and U-bolts; pot stay.
8. C8 Diverter at the back of the header with a vent line into the vent pipe.
9. C9 Relief valve on a socket with a discharge pipe to 2.3 m and a stay.
10. C10 Hose routed clear of the trailer to a coupling on the hood.
11. C11 Hood riser, flange and hung manifold; skirt riveted round the outside.
12. C12 Drum saddles, ratchet straps, suction hose and stainless feed line with clips.
13. C13 Pump and alarm box with battery and controller.
14. C14 Door with board plug, hinges and latch; damper slide in guides.

### Key results (STR-CAL-001 v0.3)

- Efficiency 51.4 % (was 53.5 %) and wood 5.6 kg/m² at 15 cm (was 5.4): **R5 and R4 still not met**, gaps about 2 points wider because the taller firebox loses 3.5 kW through its walls (was 2.6 kW).
- Coil inlet 0.108 bar, header 0.033 bar, seal limit 0.094 bar: R6 met. Water in the heated section 6.9 L: R7 met.
- Towed mass 468 kg (602 kg full): R11 mass met with 32 kg to spare; width 1.48 m at risk as before.
- Value-engineering target: USD 2,200. Estimated cost of the constructable design: USD 2,275 (USD 75 over the target).
- Status counts: 2 not met (R4, R5), 3 at risk, 1 not verifiable at TRL 3, 8 met; R12 USD 75 over the target.

### Proposed, awaiting Amish

All in the register (`docs/06-design-decisions.md`): accept STR-DDR-003; how to recover the efficiency lost to the taller firebox (A1); a seal pot overflow at the static mark (A2, a safety case change); relief discharge up or down (A3); plus the open items carried over (boiler authority ruling, jurisdiction, partners, evaporator bank, seal freezing, hood stowage, hood ballast).

### Safety concerns

- The boiler authority ruling is still the gating prerequisite: build plan safety stop S1.
- C6 corrects a real flaw: as drawn, a 1 m dip leg would have let the header reach about 0.11 bar and pushed seal water into the vent. The corrected geometry keeps 0.094 bar.
- The build plan adds stops for welding, ceramic fibre handling, cold pressure tests, never firing a dry coil and never refeeding a hot, dry coil.

### Stale media (made on Amish's Mac, not regenerated here)

`media/render-hero.png`, `media/render-exploded.png`, `media/render-detail.png`, `media/card.png` and `media/social-preview.png`, and the appearance model `cad/src/product_model.py`, show the concept: a 650 mm firebox with the coil round the fire, no skids or roof frame, the header at 1.6 m and the seal pot through the deck. They are stale and need updating.

### Recommended next step

Amish to review STR-DDR-003 and the register. Then the second paper iteration at TRL 3 (evaporator bank, controlled air and firebox shape, decisions 4 and 5). TRL 4 stays on hold.

## 2026-10-02: photoreal renders redone on the constructable design

Rendered with Blender Cycles on Amish's Mac from the updated appearance model; captioned with `.kit/photo_caption.py`; `media/card.png` and `media/social-preview.png` regenerated with `.kit/cards.py`. Views: hero, exploded, detail. image_qc passes. Appearance deviations are those logged above as proposed, awaiting Amish.

## 2026-10-03: decisions recorded

Amish decided on 2026-10-03: "Cost over target - i accept all the cost variations and overruns". Recorded for this repo: the estimated cost of USD 2,600 against the USD 2,200 target (USD 400 over).

- `docs/06-design-decisions.md`: row added to decisions made; value engineering section says the overrun was accepted by Amish on 2026-10-03.

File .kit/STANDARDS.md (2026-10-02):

---
doc_id: OHP-STD-001
title: Documentation and drawing standard
project: Open Hardware Portfolio
doc_type: Standard
version: "1.7"
status: Released
date: 2026-09-30
author: Amish Chadha
license: CC-BY-SA-4.0
revisions:
  - version: "1.0"
    date: 2026-09-24
    author: Amish Chadha
    change: First release of the standard
  - version: "1.1"
    date: 2026-09-24
    author: Amish Chadha
    change: Adopt Technology Readiness Levels (section 9) for project maturity
  - version: "1.2"
    date: 2026-09-24
    author: Amish Chadha
    change: Portfolio phase cap (section 10), concept media standard (section 11), CLAUDE.md guardrails
  - version: "1.3"
    date: 2026-09-24
    author: Amish Chadha
    change: Scale figure, interactive 3D viewer and flow diagrams added to concept media; session slash commands
  - version: "1.4"
    date: 2026-09-26
    author: Amish Chadha
    change: Every sheet and render names the project and its GitHub repository; overall dimensions, ISO centre lines and 300 dpi PNG on sheets; titles name the device and view labels state the viewing direction; optional photoreal renders with Blender
  - version: "1.5"
    date: 2026-09-27
    author: Amish Chadha
    change: Product renders (section 12), storefront images and image quality check (section 13), public release and release gate (section 14), authorship, citation and commit signing (section 15)
  - version: "1.6"
    date: 2026-09-29
    author: Amish Chadha
    change: Licensing metadata with REUSE (section 16), Zenodo DOI and Software Heritage archiving (section 17), release gate checks REUSE and a single CITATION.cff license, archive.py
  - version: "1.7"
    date: 2026-09-30
    author: Amish Chadha
    change: Concept and constructable design states; design decisions register (DEC) kept apart from the build plan; prototype build plan (BLD, section 18) with pictures by component is required TRL 3 evidence; every repo targets TRL 3 during the populate phase; build_views.py; /to-trl3 and /build-plan commands
---

# Documentation and drawing standard

Every project in the portfolio uses this standard, so that each precis, write-up and sketch looks the same and carries its own version history. The standard ships as a kit in each repo's `.kit/` folder. The kit version is in `.kit/KIT_VERSION`.

## 1. Document types and IDs

Every controlled document has a unique ID in the form `PRJ-TYP-NNN`.

- `PRJ` is the three-letter project code listed in section 7.
- `TYP` is the document type code from the table below.
- `NNN` is a sequence number within that project and type, starting at 001.

| Code | Type | Typical file |
| --- | --- | --- |
| PRC | Design precis | `docs/02-concept.md` |
| PRB | Problem statement | `docs/01-problem.md` |
| REQ | Requirements | `docs/03-requirements.md` |
| CAL | Calculation or sizing note | `docs/04-calcs/*.md` |
| DDR | Design decision record | `docs/decisions/*.md` |
| BOM | Bill of materials | `bom/bom.csv` |
| DWG | Drawing or sketch sheet | `cad/drawings/*.svg` |
| BLD | Prototype build plan (section 18) | `docs/05-build-plan.md` |
| DEC | Design decisions register (section 18) | `docs/06-design-decisions.md` |
| TST | Test plan or test report (front matter adds `environment: lab` or `relevant`) | `docs/05-tests/*.md` |

Example: `TBK-PRC-001` is the ThermaBrick design precis.

## 2. Revision scheme

| Artifact | While in draft | When released | Change after release |
| --- | --- | --- | --- |
| Documents | 0.1, 0.2, 0.3 ... | 1.0 | 1.1 for minor edits, 2.0 for a design change |
| Drawings | Rev P1, P2 ... (preliminary) | Rev A | Rev B, C ... |

- Every change to a controlled document adds a row to its revision history before the commit.
- The `version` field in front matter always equals the newest row in `revisions`. The renderer rejects a document where they differ.
- Status is one of `Draft`, `In review`, `Released` or `Superseded`. Draft and In review documents print with a status band on every page.
- Every release is tagged in Git as `<doc_id>/v<version>`, for example `TBK-PRC-001/v1.0`. Drawings are tagged `TBK-DWG-001/revA`.
- Git history is the full audit trail. The in-document revision table is the human-readable summary.

## 3. Document front matter

Every Markdown document under version control starts with this block:

```yaml
---
doc_id: TBK-PRC-001
title: ThermaBrick design precis
project: ThermaBrick
doc_type: Precis
version: "0.1"
status: Draft
date: 2026-09-24
author: Amish Chadha
license: CERN-OHL-S-2.0
revisions:
  - version: "0.1"
    date: 2026-09-24
    author: Amish Chadha
    change: Initial draft
---
```

Quote version numbers so YAML keeps `1.0` as text instead of turning it into a number. List revisions newest last.

## 4. Writing style

- Chicago Manual of Style.
- No em dashes. Restructure the sentence instead.
- Lead each section with its conclusion, then support it.
- SI units throughout, in the form `12 kW`, `450 °C`, `3.2 m`. Imperial values may follow in parentheses.
- Number every figure and table ("Figure 2", "Table 1") and give each a caption.
- State every assumption in the calculation that depends on it.
- Put safety notes in a blockquote starting with **Safety:**.

## 5. Visual identity

| Element | Specification |
| --- | --- |
| Typeface | IBM Plex Sans for text, IBM Plex Mono for code and values (SIL Open Font License, bundled in `.kit/fonts`) |
| Ink | `#111827` |
| Secondary text | `#4B5563` |
| Rules and grid | `#D1D5DB` |
| Accent (one only) | `#0F766E` teal |
| Document page | US Letter, 20 mm margins |
| Drawing sheet | ANSI B landscape (431.8 x 279.4 mm) |
| Footer | Document ID, version, status, license and designmolecule.com on every page |

## 6. Drawing and sketch conventions

- Units are millimeters unless the title block says otherwise.
- Third-angle projection, marked with the symbol in the title block.
- Line weights: visible outlines 0.5 mm, hidden lines 0.25 mm dashed, center lines 0.18 mm chain.
- The title block contains the project, title, drawing number, revision, scale, units, projection, sheet, author, date, material or notes, and license.
- Every sheet and every render names the project and its GitHub repository (from `repo:` in `project.yaml`), at the top of the sheet and in the title block, so a printed or forwarded sheet is never anonymous.
- The drawing title names the device, not only the drawing type (for example "Handheld near-infrared resin scanner: general arrangement").
- Every view label states its scale and viewing direction (for example "Scale 1:1; side elevation looking along +Y"), and every isometric or render states where it is seen from.
- Orthographic views generated with `add_ortho` carry overall dimensions (length and depth on the top view, height on the front view) and ISO 128 centre lines on cylinders; hidden lines are dashed. Tolerances are not shown before TRL 4.
- Sheets are exported as SVG, PDF and a 300 dpi PNG.
- The revision table in the top right of the sheet lists every revision.
- Concept sketches use the same sheet and title block and carry the label "CONCEPT, NOT FOR FABRICATION".
- Geometry comes from `cad/src/*.py` (build123d). Sheets are generated by `.kit/drawing.py` and never edited by hand.

## 7. Project codes

| Code | Project | Code | Project | Code | Project |
| --- | --- | --- | --- | --- | --- |
| TBK | ThermaBrick | PCF | PicoFlow | HLT | HelioLite |
| CCB | CharCube | DRN | DustRunner | TRT | TremorTrace |
| STC | StepCue | FXH | FlexHand | CPD | ColdPod |
| SCL | SunClave | STR | SteamRoot | GGD | GrainGuard |
| SDL | SeedLine | ZBX | ZeerBox | RMS | RootMesh |
| DWD | DewDrive | SSK | StillStack | PPR | PotPress |
| WWT | WaterWatch | LMF | LumaFlow | FCL | FieldCell |
| CNP | ConePro | CVC | CulvertCrawl | EGD | EmberGuard |
| SNF | SnapFrame | CGM | CargoMule | SCM | StepClimber |
| SWC | SwapCell | PLP | PalletPilot | FTK | FlatTrike |
| WWK | WaterWalker | GRR | GrowRider | SSP | SunSpoke |
| SGN | StepGen | PBX | PowerBox | WML | WasteWise-ml |
| WSC | WasteWise Scan | RFE | ReflowEconomy | | |
| OHP | Portfolio-wide | | | | |

## 8. Build and publish

- `python .kit/render.py` checks every controlled document and renders it to `docs/pdf/<doc_id>_v<version>.pdf`.
- `python .kit/drawing.py` (called from each project's `cad/src/sheets.py`) builds drawing sheets as SVG and PDF in `cad/drawings/`.
- The GitHub Action in `.github/workflows/docs.yml` runs the checks on every push and attaches PDFs to a GitHub Release whenever a release tag is pushed.
- Public releases follow section 14: `python .kit/release_gate.py` must pass, and the release tag is `v0.<TRL>.0` (for example `v0.3.0` at TRL 3).

## 9. Technology Readiness Level (TRL)

Each project states its maturity as a Technology Readiness Level on the NASA and US DOE 1 to 9 scale. The TRL rates this specific design, not the underlying technology. A sand battery is commercial elsewhere, but a new sand battery design starts at TRL 2 until evidence shows otherwise.

| TRL | Definition | Evidence the repo must contain |
| --- | --- | --- |
| 1 | Basic principles observed | Problem statement (PRB) |
| 2 | Technology concept formulated | Draft precis (PRC) and requirements (REQ) |
| 3 | Analytical or experimental proof of concept | Calculation note (CAL), working build123d model with STEP export, drawing sheet (DWG), priced BOM with every unit cost filled in, prototype build plan (BLD) with pictures, `design_state: constructable` |
| 4 | Components validated in the lab | Test report (TST) with `environment: lab`, build log entries |
| 5 | Validated in a relevant environment | Test report (TST) with `environment: relevant` |
| 6 | System prototype demonstrated in a relevant environment | Precis at version 1.0 or later with status Released, a drawing at a lettered revision (Rev A or later), and a system-level TST with `environment: relevant` |
| 7 to 9 | Operational demonstration through proven in service | Beyond portfolio scope; claim only with a named deployment partner and evidence |

Rules:

- `project.yaml` records `trl` (current level), `trl_target` (the level the current effort aims for) and `trl_evidence` (the files that support the claim).
- `python .kit/render.py --check` fails if the evidence for the claimed TRL is missing. CI runs this check on every push.
- Documentation alone cannot go past TRL 3. TRL 4 and above require hardware and a test report.
- TRL and visibility are independent. A repo can be public at TRL 3 as a documented design ready to build.
- A change of TRL is recorded in the build log with the date and the evidence that justified it.

## 10. Portfolio phase and TRL cap

`.kit/PHASE.yaml` sets the current phase. During the **populate** phase every repo is capped at **TRL 3**: `trl` and `trl_target` may not exceed 3, and the check fails if they do. Every repo targets the cap: `trl_target` must equal 3, so a new repo is taken all the way to TRL 3 (scaffold, populate and advance, see `/to-trl3`). Work that belongs to TRL 4 or later (building or testing hardware, test articles, test plans and reports, build-log entries, purchasing lists, PCB layouts) must not be started. The prototype build plan (BLD, section 18) is TRL 3 paper work and is required. Where it already exists it is kept, flagged in the check output, and not extended. Only Amish changes `PHASE.yaml`.

Every repo carries a `CLAUDE.md` with the working rules for AI sessions: the TRL cap, decision rights (nothing is recorded as decided unless Amish decided it), one step per session, and a mandatory `docs/REVIEW.md` before stopping.

## 11. Concept media

Every repo at TRL 2 or above explains its idea visually. Media are generated from a build123d massing model with `.kit/concept.py`, never drawn by hand, so they stay in step with the design.

| File | Required | Purpose |
| --- | --- | --- |
| `media/hero.png` | TRL 2+ | Shaded isometric render with a 1.75 m person for scale; the website card image |
| `media/concept-blueprint.png` and `.pdf` | TRL 2+ | Blueprint concept sheet: orthographic and isometric views, scale, key figures, title block |
| `media/model.glb` and `media/viewer.html` | TRL 2+ | Interactive 3D viewer (glTF plus model-viewer) for the website |
| `media/cutaway.png` | When the inside matters | Section view showing internal parts |
| `media/exploded.png` | Recommended | Exploded view with numbered callouts matching the BOM |
| `media/flow.png` | When energy or material moves | System, energy or material flow diagram with losses |

Session commands in `.claude/commands/` (`/populate`, `/advance-trl3`, `/rein-in`, `/refresh-media`) carry the standard prompts, so every Claude Code session starts from the same instructions.

At TRL 2 a massing model is enough: correct overall proportions and main components. All concept media carry "CONCEPT, NOT FOR FABRICATION". The check warns when required media are missing at TRL 2 and fails at TRL 3.

## 12. Product renders

Every repo at TRL 3 shows the product as it would look, not only as a massing model.

- `cad/src/product_model.py` is the appearance model. It defines `product_parts()` (named parts with a shape and a material), `TITLE` ("Name: what it is") and `RENDER_VIEWS`. It is for renders only: every main dimension comes from `cad/src/model.py`, never typed in again.
- Where the appearance model departs from `model.py` (a chamfer, a label, a fastener drawn for realism), record the deviation in `docs/REVIEW.md` as "Proposed, awaiting Amish".
- Scale comes from context, not from a floating figure: a hand or forearm for handheld objects, and the posed mannequin (`mannequin()` in `.kit/context_parts.py`: stand, walk, push, ride, sit, reach) for anything a person uses at body scale.
- Renders are made with `.kit/export_views.py` (one scene per view) and `.kit/photoreal.py` (Blender Cycles), then captioned with `.kit/photo_caption.py`. Files are `media/render-<view>.png`; `media/render-hero.png` is required.
- Every caption names the project, the repository and the viewing direction, and carries "CONCEPT, NOT FOR FABRICATION".
- Captions never sit on the render. `.kit/photo_caption.py` adds a header band (title, concept label, repository) above the render and a footer band (view note) below it, wraps every line to the image width, and steps the font down to a floor before adding a line.
- The README opens with `media/render-hero.png`.
- Software-only and scene repositories (no single product) may use a scene render as the hero instead of a product model.

## 13. Storefront images

Two images, both made from `media/render-hero.png` by `python .kit/cards.py .`:

| File | Size | Purpose |
| --- | --- | --- |
| `media/card.png` | 800 x 800 | Square thumbnail for the organization profile page |
| `media/social-preview.png` | 1280 x 640, under 1 MB | GitHub social preview, shown when a repository link is shared |

- The social preview shows the area, name, one-line description, the first sentence of the pitch, the brand line and the repository address. Design Molecule repos read "Design Molecule · open hardware concept, TRL n"; OpenRatio repos read "OpenRatio · research and educational prototype, TRL n".
- GitHub has no API for the social preview. Upload it under the repository's Settings, Social preview, on release day.
- Regenerate both images whenever `render-hero.png` changes.
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

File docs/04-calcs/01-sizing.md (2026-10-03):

---
doc_id: STR-CAL-001
title: SteamRoot sizing calculations
project: SteamRoot
doc_type: Calculation note
version: "0.4"
status: Draft
date: '2026-10-02'
author: Amish Chadha
license: CERN-OHL-S-2.0
revisions:
- version: "0.1"
  date: '2026-09-25'
  author: Amish Chadha
  change: First TRL 3 sizing calculations with script, assumptions and requirement status
- version: "0.2"
  date: '2026-09-25'
  author: Amish Chadha
  change: Recommendations accepted by Amish (DDR-002)
- version: "0.3"
  date: '2026-10-01'
  author: Amish Chadha
  change: "Rerun for the constructable design (STR-DDR-003): taller firebox, seal pot dip leg, tube bank, added parts; cost reported against the value-engineering target"
- version: "0.4"
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

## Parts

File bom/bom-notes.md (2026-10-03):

# BOM notes

Prices were reviewed at TRL 3 (2026-09-25). They are indicative estimates except item 10, which was checked against a live listing (SupplyHouse.com, Watts 315M2-015, $68.19 on 2026-09-25). The item 10 capacity, 375 lb/h (170 kg/h) at 3/4 in and 15 psi, is from the Watts Series 315 capacity table; it covers the dry-coil refeed flash as Amish decided on 2026-09-25. Item numbers match the callouts in `media/exploded.png` and the general arrangement drawing `cad/drawings/STR-DWG-002`. Items 13 to 16 are not drawn in the model. Item 22, the evaporator bank, is drawn and appears in the exploded view.

- **Total $2,600.00.** Value-engineering target: USD 2,200 (`budget_usd`, a hypothetical control target, not a limit; Amish, 2026-10-01). Estimated cost of the constructable design: USD 2,600 (USD 400 over the target). The 2026-10-02 decisions added line 22 (evaporator bank, $190) and repriced lines 5, 6, 9, 12, 19 and 21: the secondary air damper, one coil turn fewer, the seal pot overflow and loop seal, ballast-rated hood handles, the bank link and reducing unions, and longer and extra fixings. Each new price states its basis in the notes column of `bom.csv`; all are indicative. The total is computed by `docs/04-calcs/sizing.py`.
- The largest cost risks are the stainless coil (item 6), the evaporator bank tube (item 22), the steam hose (item 11) and the header and seal assembly (item 9). None of these should be substituted with uncertified or hot-water-rated parts to save money.
- The trailer price assumes a used unit. A new trailer would add about $400 to $700.
- Tools, welding consumables, shipping and wood fuel are not included.
- This is a priced bill of materials for TRL 3 evidence, not a purchasing list. Nothing should be bought before the regulatory ruling (see `docs/REVIEW.md`).

Mass: the made parts are weighed from the model volumes (`python cad/src/model.py --mass`): 42.5 kg of supports and lines and 26.0 kg of evaporator bank. The machine weighs about 499 kg as towed with the drum and seal pot drained and both hoods aboard, 633 kg full (STR-CAL-001 v0.4).

> **Safety:** Items 9, 10, 11, 15 and 16 are safety parts. Buy them new, rated for saturated steam where relevant, and keep the receipts and ratings with the design records.

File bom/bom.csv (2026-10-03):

item | qty | spec | supplier | unit_cost_usd | make_buy | notes
1 Trailer frame and drawbar | 1 | Used single-axle garden or utility trailer, deck about 2.0 x 1.2 m, rated 750 kg or more, tare about 160 kg | Local used market (classifieds or farm auction) | 200.00 | buy | Indicative price; towed drained at about 499 kg, but the axle rating must cover the 633 kg full mass on site (CAL-001 v0.4); a new trailer adds about $400 to $700 | [' but the axle rating must cover the 536 kg full mass on site (CAL-001); a new trailer adds about $400 to $700']
2 Wheels | 2 | Trailer wheels and tires, about 460 mm diameter | Included with trailer | 0.00 | buy | Included with the used trailer
3 Feed water tank | 1 | 125 L HDPE drum with bulkhead outlet, strainer and level sight tube | Farm supply store | 60.00 | buy | Indicative price; 4.2 h of steaming at 30 kg/h (CAL-001)
4 Feed pump | 1 | 12 V diaphragm pump, about 4 L/min, 3 bar shut-off, with needle valve and rotameter flow meter | Online retailer (RV and agricultural spray pumps) | 45.00 | buy | Indicative price; runs at 0.5 L/min against about 0.1 bar
5 Firebox | 1 | 3 mm mild steel box 700 x 600 x 960 mm with a bolted roof plate on a 25 x 25 x 3 angle frame; 50 mm ceramic fiber lining (two 25 mm blanket layers with rigidizer on the walls, board on the floor and under the roof); 300 x 300 mm cast grate; door 340 x 280 mm with a fiber board plug, weld-on hinges and a turn latch; primary air damper slide in two guides under the door; secondary air slot 150 x 20 mm in the door with its own slide and guides | Self (steel from a metals supplier; lining from a kiln or stove supply) | 265.00 | make | Material cost only; 960 mm tall so the door and fire bed sit below the coil (STR-DDR-003; 40 mm lower than v0.3 with one coil turn fewer, CAL-001 v0.4); secondary damper added 2026-10-02 (about $10 of plate and flat bar, less about $5 of shell steel); castable refractory would add about 270 kg (CAL-001) and break R11
6 Monotube steam coil | 1 | Stainless steel 316 tube, 25.4 mm OD x 1.65 mm wall, 14.6 m: 10 turns on 420 mm mean diameter, two straight tails and the outlet pipe to the header | Metals supplier (stainless tube stockist) | 215.00 | buy | Indicative price, pro rata from the 16 m price (about $14.70 per m); wound in house on a former; one turn fewer than v0.3 so the evaporator bank fits within 8 L of heated water (CAL-001 v0.4); stainless decided by Amish 2026-09-25 (STR-DDR-001)
7 Flue-gas economizer | 1 | 316 stainless tube 12.7 mm OD x 1.2 mm wall, 8 m, coiled in a 520 x 460 x 260 mm 2 mm steel box with condensate drain | Self (tube from a stainless tube stockist) | 90.00 | make | Material cost only; flue gas condenses on the cold end (dew point about 45 C in CAL-001) so stainless is required
8 Chimney and spark arrestor | 1 | 150 mm single-wall stainless flue about 0.6 m, spark arrestor cap with 6 mm or finer mesh, rain cap | Stove and chimney supply | 90.00 | buy | Indicative price; outlet 2.4 m above ground
9 Steam header and water-seal vent | 1 | DN50 stainless header, 114 mm seal pot with 1 m dip leg and level sight tube, DN32 vent pipe to 2.3 m, three-way diverter valve with no closed position, steam-rated quick coupling, drain valve, fittings; seal pot overflow: 3/4 in half coupling welded to the pot at the static water mark, about 2.6 m of 3/4 in galvanized pipe with six elbows forming a 350 mm loop seal and a down-pipe to 80 mm above the ground behind the deck, trap drain plug, trap stay and rear clip | Plumbing and steam fittings supply | 220.00 | buy | Indicative price; overflow added 2026-10-02 at about $70 (pipe about $3 per ft, malleable elbows and half coupling about $4 each, plug, flat bar and clamp about $15; typical hardware store prices, not checked live); seal limit 0.084 bar gauge with the overflow (CAL-001 v0.4); diverter must never isolate the coil from the vent
10 Certified relief valve | 1 | ASME Section IV bronze steam safety valve, 15 psi (1.03 bar) set, 3/4 in NPT, for example Watts 315M2-015 | SupplyHouse.com (listed at $68.19 on 2026-09-25) | 70.00 | buy | Maker's capacity table (Watts Series 315) gives 375 lb/h (170 kg/h) at 3/4 in and 15 psi; covers 30 kg/h and the 155 kg/h dry-coil refeed flash (CAL-001; sizing decided by Amish 2026-09-25); confirm for the unit bought; never adjust or plug
11 Steam hose | 1 | EPDM saturated-steam hose, 25 mm bore, 6 m, ground-joint couplings and whip checks | Industrial hose supplier (made-up assembly) | 180.00 | buy | Indicative price; steam rated not hot-water rated; moved between hoods only after steam is diverted to the vent
12 Steam hood | 2 | 1.2 x 1.0 x 0.25 m open-bottom pan, 1 mm aluminum double skin, 40 mm mineral wool, 60 mm galvanized soil skirt, perforated steam manifold; handles of 30 x 30 x 2.5 mm steel tube on 30 mm standoffs with 100 x 100 x 3 mm foot plates through-bolted to backing plates inside, sized for 40 kg of ballast weights a hood | Self (sheet from a metals supplier) | 155.00 | make | Material cost per hood; two hoods used alternately (decided by Amish 2026-09-25); handles sized for ballast (decided 2026-10-02) add about $15 a hood (1.8 m of steel tube about $8, plates and M6 bolts about $7); the ballast weights themselves are not included until TRL 4 soil tests set them
13 Battery | 1 | 12 V 20 Ah sealed lead acid for the feed pump and alarms | Farm or auto parts store | 60.00 | buy | Indicative price; lead acid chosen over lithium to avoid a lithium hazard next to a fire
14 Instruments | 1 | 0 to 1 bar (0 to 15 psi) steam gauge with siphon; four type K thermocouples (two soil probes at 15 cm, coil outlet, flue) with a four-channel handheld reader | Instrument supplier (online) | 90.00 | buy | Indicative price
15 Safety kit | 1 | Personal CO alarm, 2A:10B:C fire extinguisher, heat-resistant gloves, face shield | Hardware store | 100.00 | buy | Indicative price; required before first fire
16 Feed and coil alarms | 1 | Type K coil outlet temperature alarm controller with buzzer (set about 150 C), tank low-level float switch, fuse, wiring and small enclosure | Online retailer (panel controllers) | 60.00 | buy | Indicative price; fixed pump rate with coil outlet alarm decided by Amish 2026-09-25; not drawn
17 Steelwork for supports | 1 | Two firebox skids (50 x 50 x 3 mm square tube, 1.2 m each); header post (50 x 50 x 3 mm square tube about 1.0 m with a 150 x 150 x 10 mm foot plate and a saddle plate); 200 x 200 x 10 mm pot foot plate; pot stay (40 x 6 mm flat bar and a clamp band); two hardwood drum saddles (400 x 100 x 40 mm, two layers each) | Metals supplier and timber yard | 70.00 | make | Added for construction (STR-DDR-003); indicative price
18 Firebox internals and glands | 1 | Three coil brackets (40 x 40 x 5 mm 316 stainless angle, about 0.4 m in all); grate stand (25 x 25 x 2 mm square tube about 2.2 m and four 60 x 60 x 5 mm pads); two 6 mm steel gland plates 80 x 100 mm; 2 m of 12 mm ceramic rope packing | Metals supplier; stove supply for the rope | 50.00 | make | Added for construction (STR-DDR-003); indicative price
19 Feed lines and fittings | 1 | 316 stainless tube 12.7 mm OD x 1.2 mm wall, 3.9 m (feed line, coil inlet jumper and the economizer to bank link); 1 m of 16 mm reinforced suction hose with clips; stainless compression fittings: two 25.4 mm unions, one 25.4 to 12.7 mm reducer, two 12.7 mm bulkhead unions for the economizer, pump fittings; two feed line clips; two 15.88 to 12.7 mm (5/8 to 1/2 in) stainless reducing unions for the bank tails | Stainless fittings supplier (online) | 140.00 | buy | Added for construction (STR-DDR-003); indicative price; the bank link and two reducing unions added 2026-10-02 at about $45 (stainless reducing compression unions about $20 each)
20 Relief discharge and vent line | 1 | 3/4 in steel pipe about 0.8 m with one elbow (relief valve discharge to 2.3 m, open end, drain hole at the low point); 1 in steel pipe about 0.9 m with two elbows and a tee into the vent pipe (diverter vent line); 12 mm round bar stay | Plumbing and steam fittings supply | 45.00 | buy | Added for construction (STR-DDR-003); the discharge pipe is never valved, capped or joined to another line
21 Fixings and straps | 1 | Zinc-plated or stainless bolts with nyloc nuts: 4 x M12 x 160 (skids), 12 x M10 (post, pot foot, saddles), 14 x M8 x 35 (roof, through the bank box frame), 12 x M8 weld studs (economizer flange), 8 x M6 (lid), 8 x M6 weld studs (gland plates); two M8 U-bolts for 60 mm pipe; two 25 mm ratchet straps with deck lashing points; ceramic rope gasket 4 m; 2 x M8 (overflow clip), 2 x M5 (bank slot cover), 16 x M6 (hood handle foot plates) | Hardware store | 50.00 | buy | Added for construction (STR-DDR-003); indicative price; fixings for the bank box, overflow and handles add about $5
22 Evaporator bank | 1 | 316 stainless tube 15.88 mm OD x 1.24 mm wall (5/8 x 0.049 in), 7 m, bent into a serpentine of two layers of five runs on a 47.6 mm bend radius (6.4 m in the box); box 700 x 600 x 170 mm of 2 mm steel on a 25 x 25 x 3 angle frame, clamped by the roof bolts between the firebox roof and the economizer; 25 mm ceramic fiber blanket and board lining; two 6 mm support bars and two spacers; tail slot cover | Self (tube from a stainless tube stockist; steel from a metals supplier; lining from a kiln or stove supply) | 190.00 | make | Added 2026-10-02 (STR-DDR-002 item 1; CAL-001 v0.4, section 4); indicative: welded 316 tube about $15 per m ($105), sheet and angle about $45, lining about $30, bars about $10; brings efficiency to about 69 % with the dampers set

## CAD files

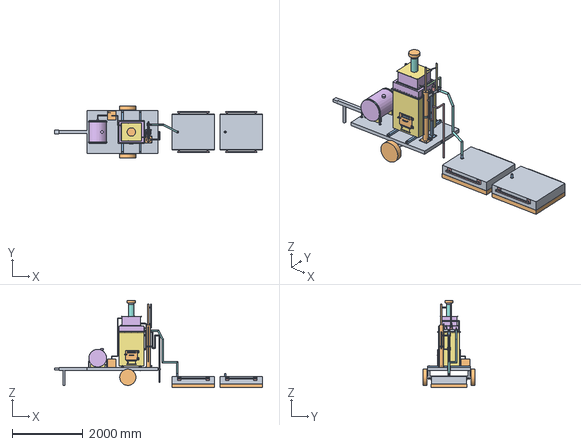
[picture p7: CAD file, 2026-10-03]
cad/step/steamroot.step
5871.5 x 1480.0 x 2460.0 mm

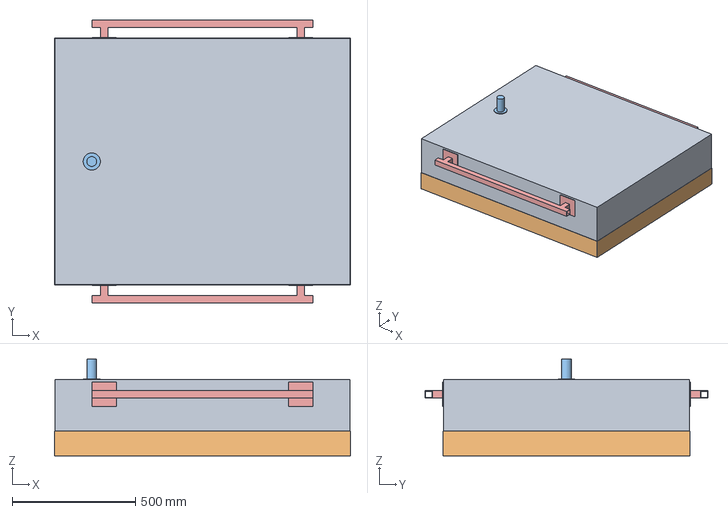
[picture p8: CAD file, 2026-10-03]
cad/step/steamroot-hood.step
1203.0 x 1150.0 x 393.0 mm

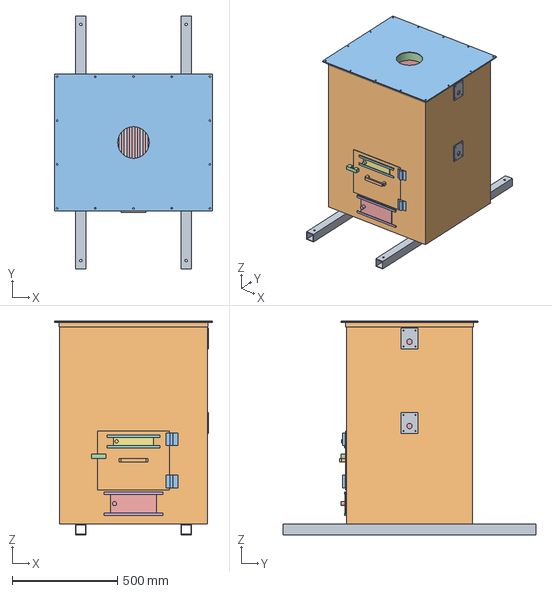
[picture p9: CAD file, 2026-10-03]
cad/step/steamroot-firebox.step
750.0 x 1200.0 x 1013.0 mm

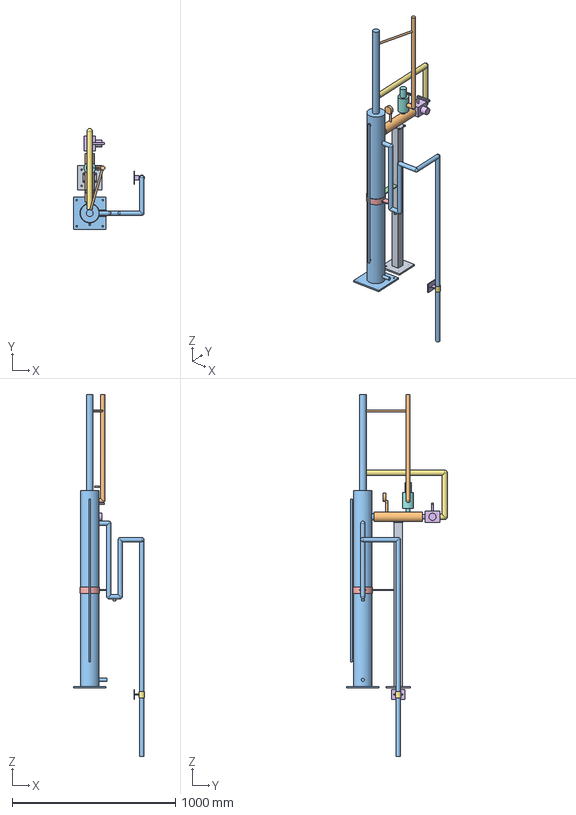
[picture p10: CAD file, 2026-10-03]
cad/step/steamroot-header.step
436.3 x 618.8 x 2220.0 mm

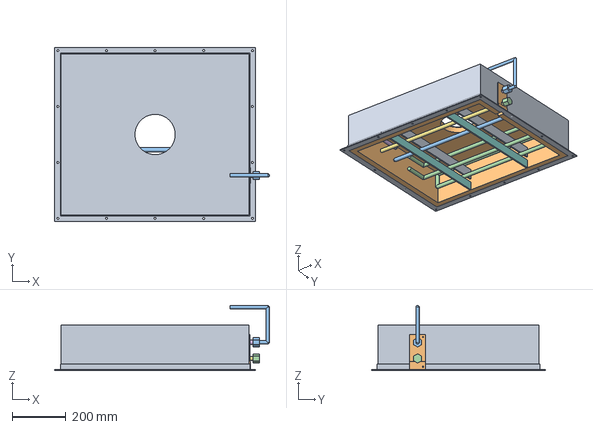
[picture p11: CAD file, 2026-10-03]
cad/step/steamroot-bank.step
801.4 x 650.0 x 242.3 mm

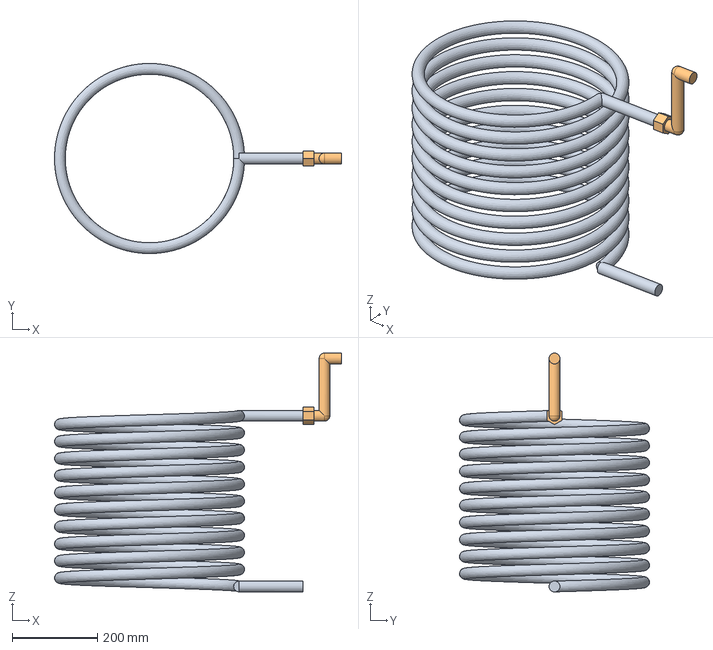
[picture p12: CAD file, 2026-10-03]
cad/step/steamroot-coil.step
672.5 x 445.4 x 559.7 mm

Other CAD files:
cad/stl/steamroot-bank.stl
cad/stl/steamroot-coil.stl
cad/stl/steamroot-firebox.stl
cad/stl/steamroot-header.stl
cad/stl/steamroot-hood.stl
cad/stl/steamroot.stl

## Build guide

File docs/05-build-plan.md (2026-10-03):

---
doc_id: STR-BLD-001
title: SteamRoot prototype build plan
project: SteamRoot
doc_type: Build plan
version: "0.3"
status: Draft
date: '2026-10-02'
author: Amish Chadha
license: CERN-OHL-S-2.0
revisions:
  - version: "0.1"
    date: '2026-10-01'
    author: Amish Chadha
    change: First build plan, with pictures by component and step; design made constructable (STR-DDR-003)
  - version: "0.2"
    date: '2026-10-02'
    author: Amish Chadha
    change: "STR-DDR-003 recorded as accepted; safety stops from Amish's 2026-10-02 decisions: authority named in S1, ice check in S4, hoods on a second vehicle in S9, seal pot draining rule S10"
  - version: "0.3"
    date: '2026-10-02'
    author: Amish Chadha
    change: "Approved 2026-10-02 decisions carried into the design: evaporator bank box between the roof and the economizer, 960 mm firebox and 10-turn coil, secondary air damper on the door, seal pot overflow with a loop seal, hood handles sized for ballast; pictures and sketches STR-DWG-101 to 126 regenerated"
---

# SteamRoot prototype build plan

**Plan, not yet built.** How to build the first proof-of-concept prototype, component by component. Building and testing to it is TRL 4 work. Decisions still to be made are kept in the design decisions register ([docs/06-design-decisions.md](06-design-decisions.md)), not here.

> **Safety:** Nothing in this plan may be bought, built or fired until there is a written ruling from the local boiler authority on this open-vented, wood-fired steam coil (safety stop S1). SteamRoot combines an open fire, carbon monoxide and steam that burns skin in under a second. The steam side must always be open to the air through the water-seal vent: never fit a valve, cap or plug that could shut it. Welding, grinding and cutting ceramic fibre each have their own hazards, given in section 6.

## 1. What you are building

Figure 1. Every component, pulled apart and numbered in build order

*Figure 1. Every component pulled apart and numbered in build order; the second hood is the same as the first.*

The prototype is a small wood-fired steam generator on a used single-axle trailer, with two insulated steam hoods that are pressed onto a soil bed. On the trailer stand a lined steel firebox with a stainless steel coil above the fire and two air dampers, an evaporator bank box, a flue-gas economizer and a chimney stacked on the firebox roof, a steam header on a post with its water-seal pot, overflow, vent, relief valve and diverter, a feed water drum on two saddles, and a box holding the feed pump, battery and alarms. A 6 m steam hose takes the steam to whichever hood is in use. Figure 1 shows the 31 components in the order you make or fit them. Most are made in a farm or small fabrication workshop: the firebox shell, roof, skids, brackets, grate stand, door and dampers are cut and welded from mild steel sheet, tube and angle; the coil and the evaporator bank are each bent from one length of stainless tube; the bank box, the economizer box and its tube bank, the header, seal pot, overflow and post are made from sheet, pipe and tube; the hoods are folded and riveted from aluminium and galvanised sheet. Everything else is bought: the trailer, the ceramic fibre lining, the cast grate, the chimney and spark arrestor, the certified relief valve, the diverter, the hose, the drum, the pump and the alarms. The parts cost about $2,600 from the bill of materials.

## 2. What changed to make it buildable

The concept showed what SteamRoot does; some of its parts could not be made, fixed or put together as drawn. Each change below keeps what the machine does, and all of them are recorded in decision record STR-DDR-003, accepted by Amish on 2026-10-02.

*Table 1. Changes from the concept.*

| Component | The concept had | The buildable design has | Why |
| --- | --- | --- | --- |
| Firebox and coil | A 650 mm firebox with the coil wound round the fire from near the floor to the roof; nowhere to load wood | A 960 mm firebox with the door, grate and air inlets below the coil and 280 mm of fire space (Figure 9) | Wood has to go in through a door onto a grate the coil does not surround |
| Coil support | None | Three stainless brackets welded to the shell through the lining (Figure 6) | The coil rests on them and can grow when hot |
| Coil fitting | A welded box the coil could not enter; tails through the wall with no holes, crossing outside | A bolted roof; the coil goes in from the top and its tails slide out through slots closed by gland plates; unions outside (Figure 15) | The coil can be fitted, removed and allowed to grow |
| Economizer | A solid box, not fixed, with the coil inlet ending beside it | A bolted box on the roof with a serpentine tube bank inside, a lid carrying the chimney, and unions to the feed line and, through the evaporator bank, the coil (Figure 18) | The feed water has a path from the pump to the coil |
| Firebox fixing | Standing loose on the deck | Two skids welded under the firebox, bolted into the trailer's side rails (Figure 4) | Held for towing, with an air gap under the hot floor |
| Water-seal pot | Reached through the deck; a 1 m dip leg that would have let the header reach about 0.11 bar | A pot on a foot plate with an 890 mm dip leg and an overflow at the water mark, so the seal blows at 0.084 bar and the pot cannot be overfilled (Figure 25) | Keeps the seal under the 0.094 bar limit and keeps water out of the vent |
| Header | Hung on the coil tube | A post with a saddle and U-bolts, and a stay to the pot (Figure 22) | The coil is not a structure |
| Diverter, relief valve | No pipe from the diverter to the vent; relief valve with no discharge pipe | A vent line from the diverter into the vent pipe; a relief discharge pipe to 2.3 m (Figure 22) | Steam always has a safe way out |
| Hose and hood | The hose passed through the deck and the hood; the manifold floated | A coupling on top of each hood, a riser to the hung manifold, a riveted skirt (Figure 32) | Every joint is made, not drawn through |
| Drum and feed | A cradle cut through the drum; no feed lines | Two hardwood saddles, ratchet straps, a suction hose and a stainless feed line (Figure 28) | The drum is held for towing and the water reaches the coil |

## 3. Making the components

Make and check each component before the assembly step that needs it. Sizes are in millimetres. "Front" is the operator side, where the firebox door is; "left" and "right" are as seen standing at the front facing the machine, so the drawbar is on the left and the hoods on the right. Heights are above the ground with the trailer level unless a step says otherwise. Workshop tolerance is 1 mm on steelwork and 0.5 mm on drilled holes unless a step says otherwise; drawings do not carry tolerances before TRL 4.

### 3.1 Trailer (bought, used)

**What it is.** A used single-axle garden or utility trailer with a flat deck about 2.0 x 1.2 m, about 500 above the ground, with steel side rails about 80 deep, rated for 750 kg or more.

**What to do to it.** Clean and check the deck, the side rails, the axle, the tyres, the lights and the coupling, and repair anything worn. Mark the deck centre line. Drill the holes for the skids (section 3.3), the header post and pot foot plates (sections 3.15 and 3.17), the drum saddles (section 3.19) and the pump box (section 3.23) once those parts are made, by marking through them in place.

**Check before moving on.** The trailer stands level on its jack; the axle rating on its plate covers 602 kg.

### 3.2 Firebox shell

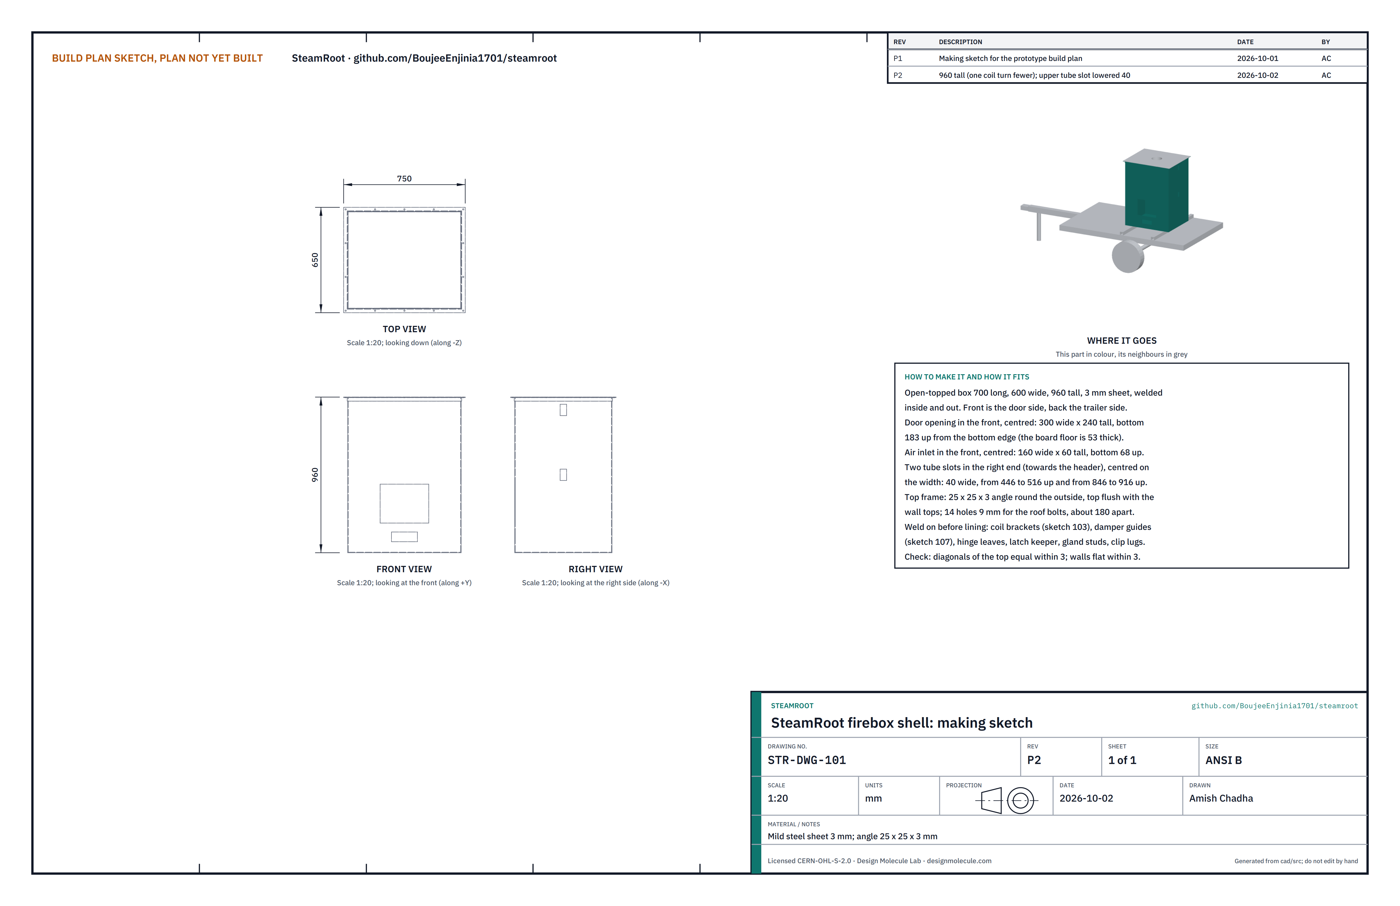
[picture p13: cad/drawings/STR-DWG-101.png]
Figure 2. Making sketch of the firebox shell


*Figure 2. Firebox shell making sketch (STR-DWG-101).*

**What it is and what it is made from.** The steel box that holds the lining, the grate and the coil. Mild steel sheet 3 mm, welded, open at the top, 700 long, 600 wide and 960 tall, with a frame of 25 x 25 x 3 mm angle round the top edge for the roof bolts.

**How to make it.**

1. Cut the floor 700 x 600, the front and back 700 x 957 and the two ends 594 x 957 from 3 mm sheet. Mark the inside faces.
2. In the front, cut the door opening 300 wide x 240 tall, centred, its bottom 183 above the bottom edge of the box, and the air inlet 160 wide x 60 tall, centred, its bottom 68 above. Round the corners to about 5 and file the edges.
3. In the right end, cut the two tube slots 40 wide, centred on the width: one from 446 to 516 above the bottom edge, the other from 846 to 916.
4. Tack the walls to the floor and to each other, check the box is square (diagonals of the top within 3), then weld all seams inside and out.
5. Weld the 25 x 25 x 3 angle frame round the outside of the top edge, mitred at the corners, its top flush with the wall tops. Drill 14 holes of 9 mm through the frame, 12.5 out from the walls: five along each long side and two more at each end, evenly spaced.
6. Weld on, before the lining goes in: the coil brackets inside (section 3.4); the damper guides, the hinge leaves and the latch keeper outside on the front (sections 3.7 and 3.8); four M6 studs round each tube slot (section 3.10); two clip lugs on the left end for the feed line, 190 behind the centre line, 400 and 850 above the bottom edge.
7. Fit stainless lining pins on the inside walls about 250 apart (section 3.5). Paint the outside with high-temperature paint.

**How it fits the parts next to it.** The floor sits on two skids (Figure 4). The roof bolts down onto the angle frame (section 3.11). The evaporator bank box and the economizer stand on the roof, not on the shell.

**Check before moving on.** The walls are flat within 3; the door opening and slots are where Figure 2 shows; a 40 mm bar passes freely through each slot.

### 3.3 Firebox skids (make 2)

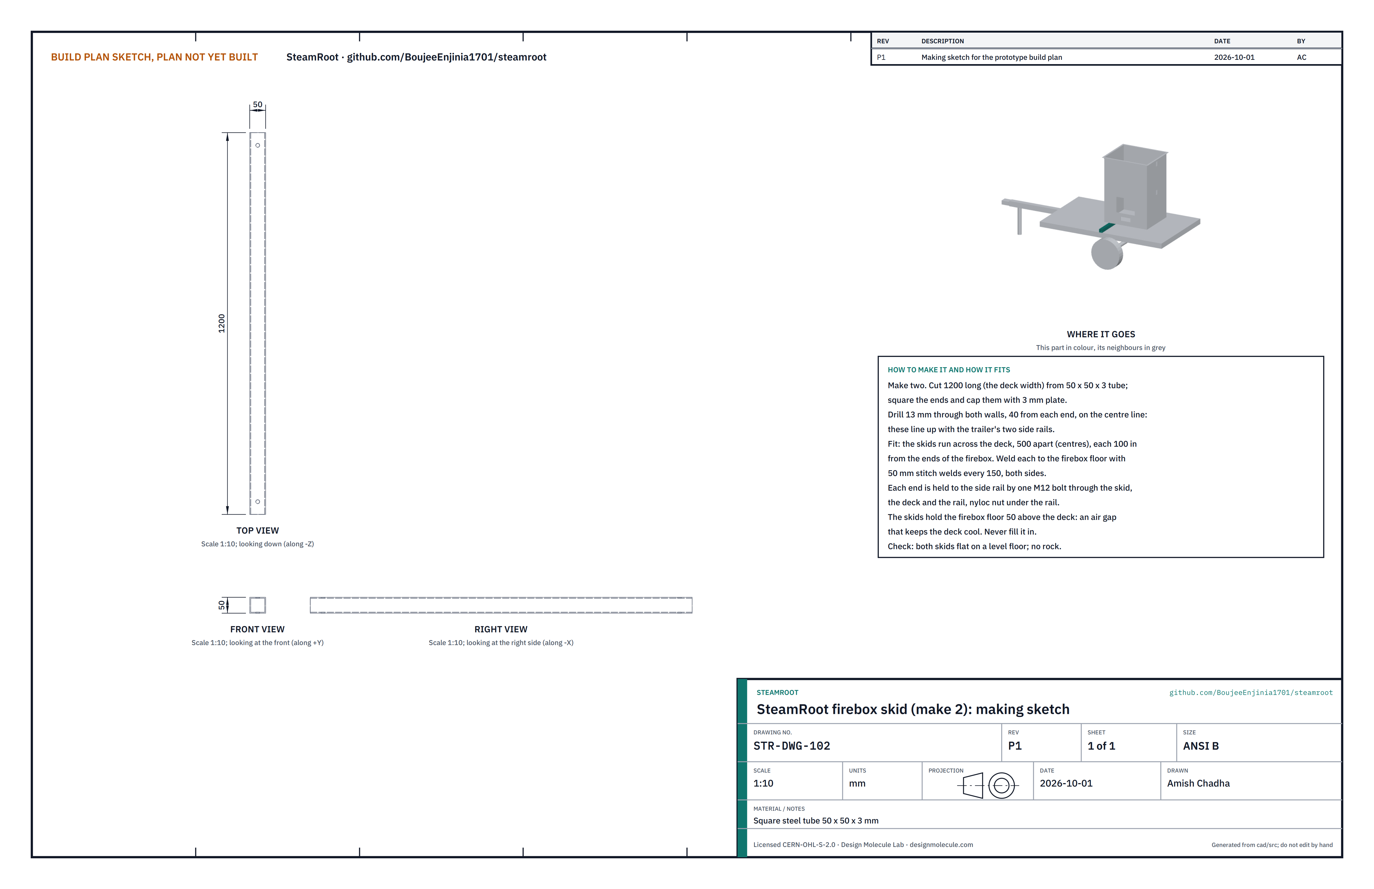
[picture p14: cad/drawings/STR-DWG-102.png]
Figure 3. Making sketch of the firebox skid


*Figure 3. Firebox skid making sketch (STR-DWG-102).*

**What it is and what it is made from.** Two lengths of square tube that run across the deck under the firebox; their ends bolt into the trailer's side rails. Square steel tube 50 x 50 x 3 mm.

**How to make it.**

1. Cut two lengths of 1200 (the deck width); square the ends and weld a 3 mm cap on each.
2. Drill 13 mm through both walls, 40 from each end, on the centre line.
3. Turn the firebox over. Lay the skids across its floor, 500 apart (centres), each 100 in from an end, overhanging equally front and back. Stitch weld each to the floor, 50 long every 150, on both sides.

**How it fits the parts next to it.**

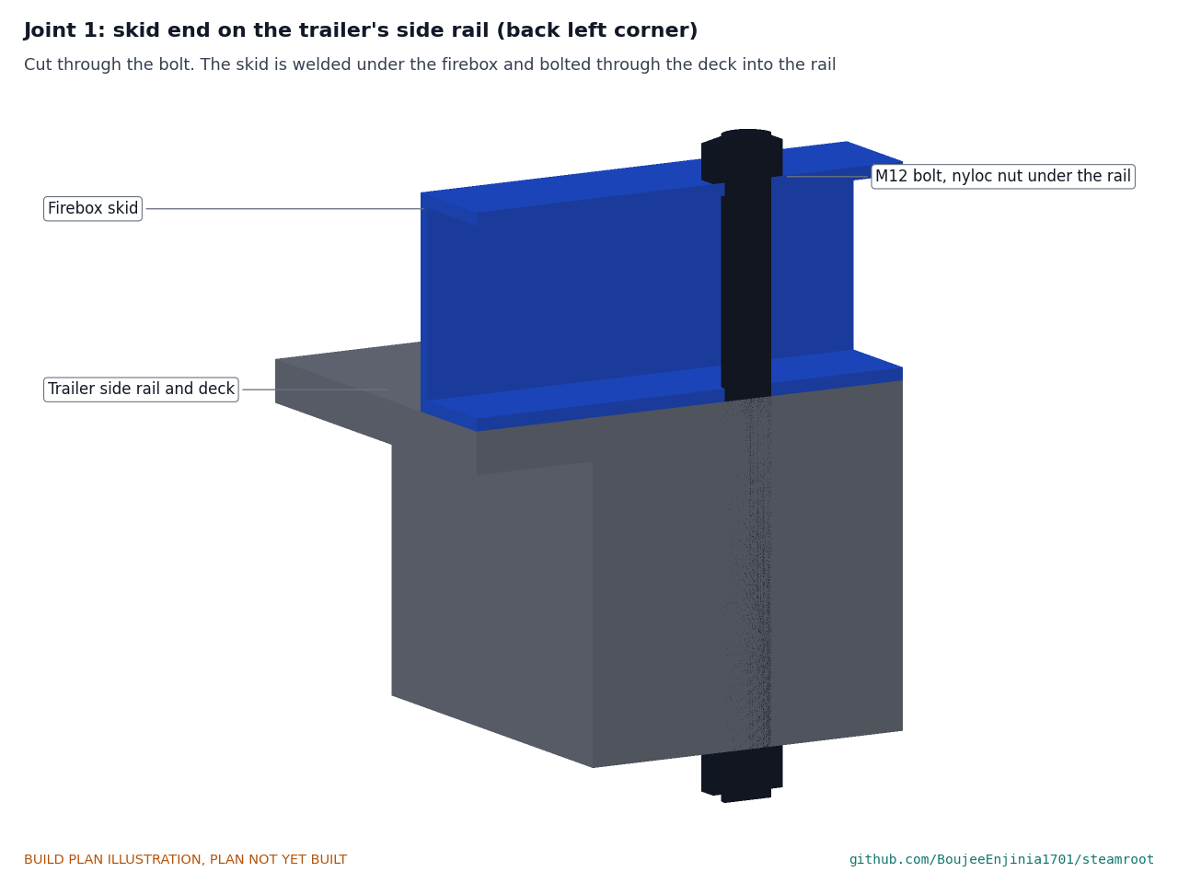
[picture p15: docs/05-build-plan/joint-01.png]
Figure 4. Joint 1: skid end on the side rail


*Figure 4. Each skid end is held by one M12 bolt through the skid, the deck and the side rail, with a nyloc nut under the rail.*

The skids hold the firebox floor 50 above the deck. That air gap keeps the deck cool: never fill it.

**Check before moving on.** The firebox stands on a level floor on its skids without rocking.

### 3.4 Coil brackets (make 3)

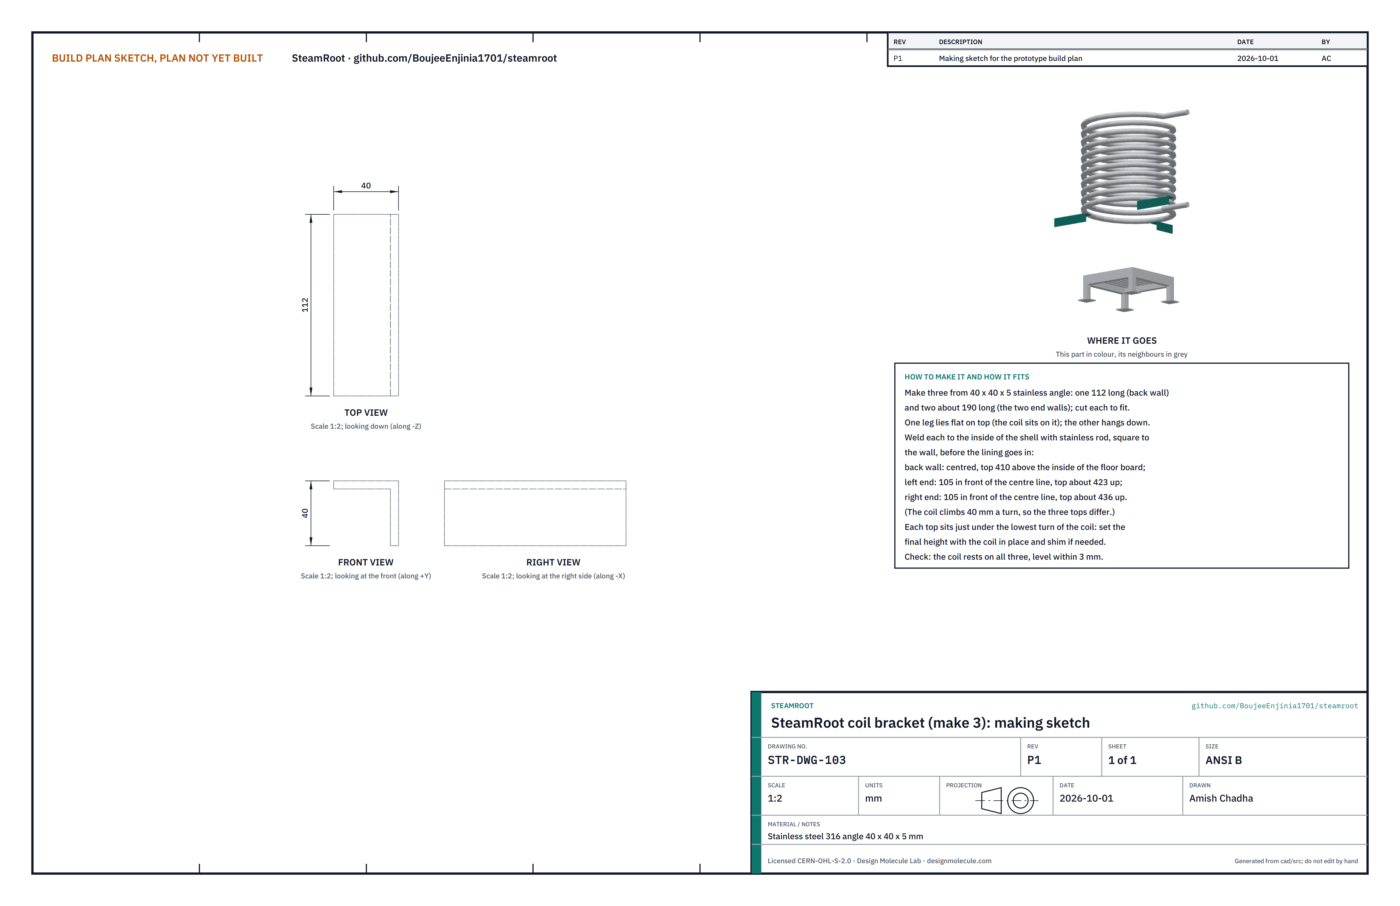
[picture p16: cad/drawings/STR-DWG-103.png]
Figure 5. Making sketch of the coil bracket


*Figure 5. Coil bracket making sketch (STR-DWG-103).*

**What it is and what it is made from.** Three short angles welded inside the firebox that carry the lowest turn of the coil. Stainless steel 316 angle 40 x 40 x 5 mm.

**How to make it.**

1. Cut one 112 long and two about 190 long; deburr.
2. Weld each to the inside of the shell with stainless rod (309 type for stainless to mild steel), the flat leg on top and the other leg hanging down: the short one in the middle of the back wall, its top 410 above the inside of the floor board (463 above the bottom of the shell); one on each end wall, 105 in front of the centre line, tops about 423 (left) and 436 (right) above the floor board. The coil climbs 40 mm a turn, so the three tops differ.
3. Set the final heights with the coil in place (step 7) and shim under the coil if needed.

**How it fits the parts next to it.**

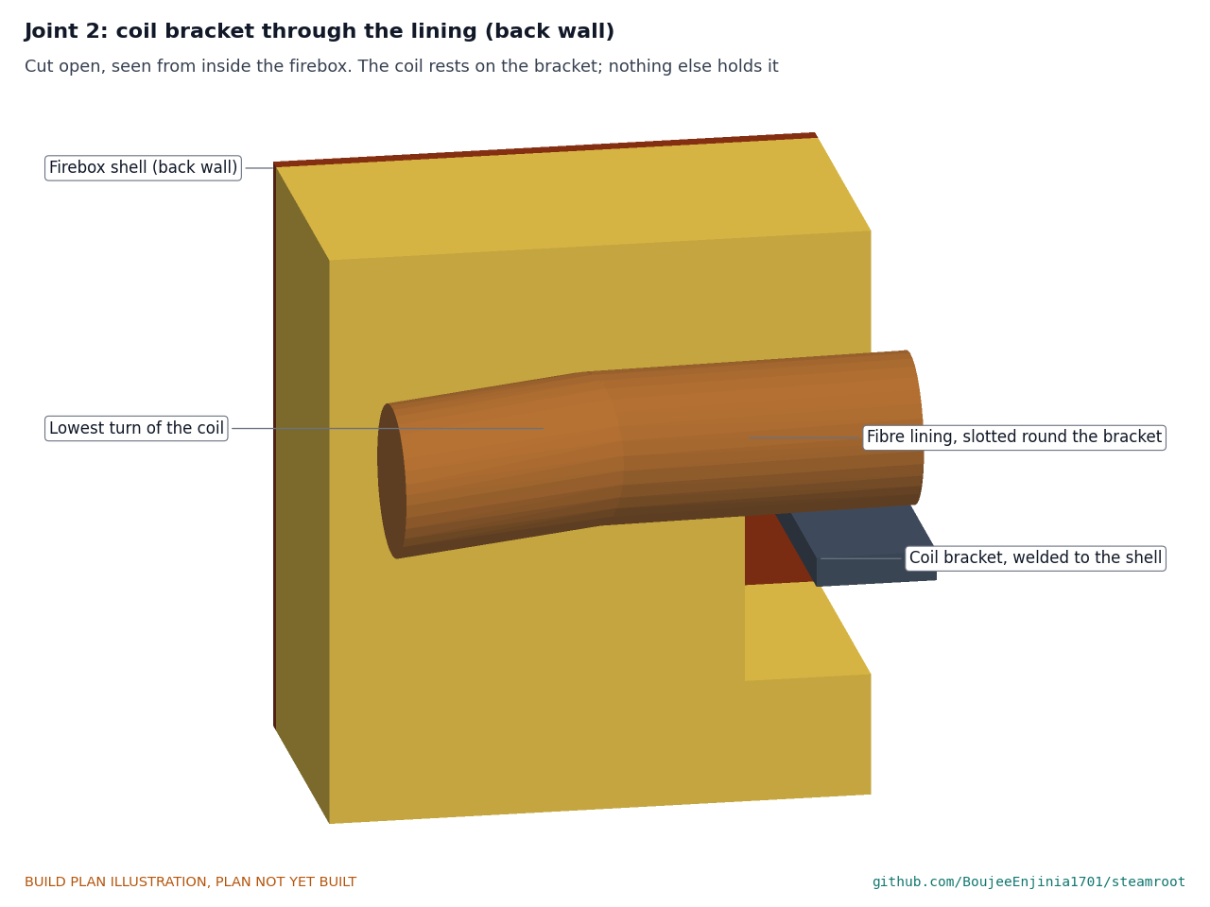
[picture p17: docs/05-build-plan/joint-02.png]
Figure 6. Joint 2: coil bracket through the lining


*Figure 6. The bracket passes through a slot in the lining; the lowest turn of the coil rests on it. Nothing else holds the coil.*

**Check before moving on.** All three brackets are level across and square to their walls.

### 3.5 Fibre lining (bought, cut to fit)

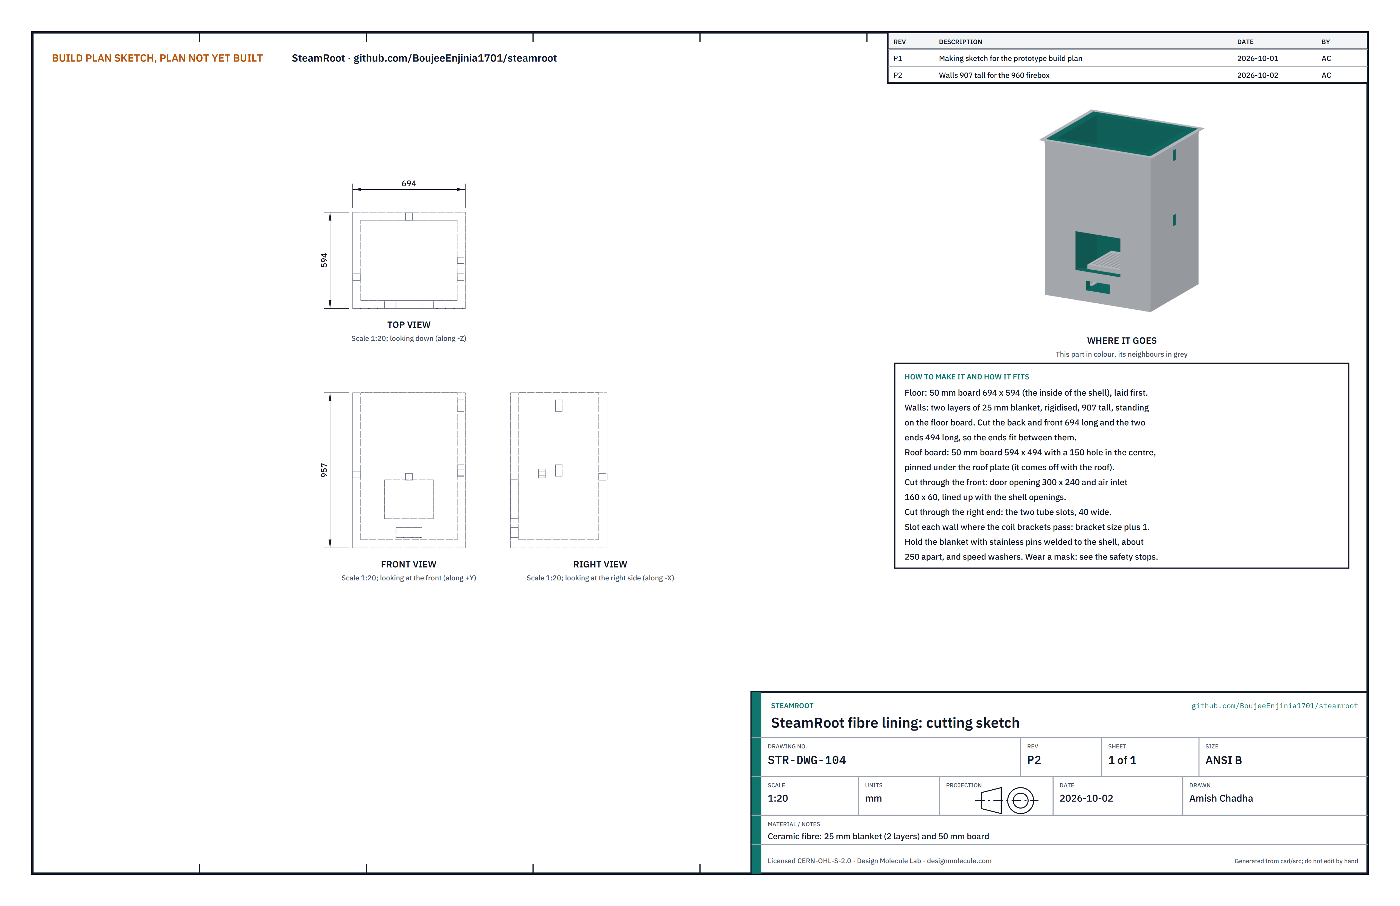
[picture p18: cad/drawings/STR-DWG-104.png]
Figure 7. Cutting sketch of the fibre lining


*Figure 7. Fibre lining cutting sketch (STR-DWG-104).*

**What it is and what it is made from.** The insulation inside the firebox: 50 mm ceramic fibre board on the floor and under the roof, and two layers of 25 mm rigidised ceramic fibre blanket on the walls.

**How to make it.**

1. Cut the floor board 694 x 594 and lay it in first.
2. Cut each layer of wall blanket 907 tall: the back and front 694 long, the two ends 494 long so they fit between them. Cut through the front for the door opening (300 x 240) and air inlet (160 x 60), and through the right end for the two tube slots, each lined up with the shell. Slot the blanket where the brackets pass (bracket size plus 1).
3. Press each layer over the pins, the joints of the second layer staggered from the first, and hold it with speed washers. Brush on rigidizer.
4. Cut the roof board 594 x 494 with a 150 hole in the centre; it goes on the roof (section 3.11).

**How it fits the parts next to it.** The walls stand on the floor board; the roof board fits inside the tops of the walls (Figure 18).

**Check before moving on.** No steel shows inside except the bracket tops and the pins; the lining is 50 thick everywhere.

### 3.6 Grate stand and cast grate

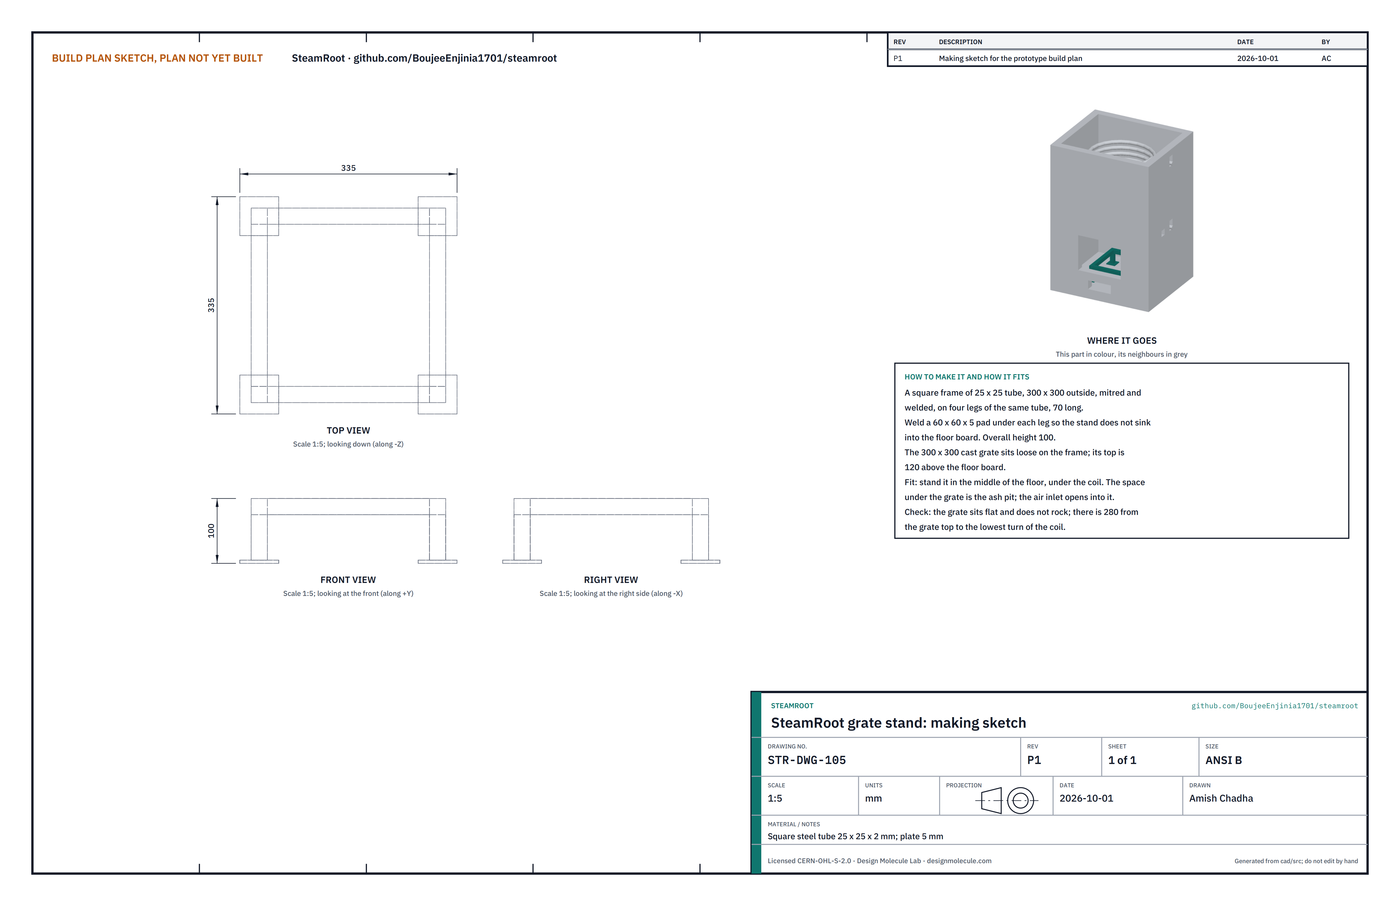
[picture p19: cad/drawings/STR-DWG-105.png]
Figure 8. Making sketch of the grate stand


*Figure 8. Grate stand making sketch (STR-DWG-105).*

**What it is and what it is made from.** A small table that holds the cast grate 100 above the floor, so air comes in under the fire. Square steel tube 25 x 25 x 2 mm and 5 mm plate; a bought 300 x 300 cast iron grate.

**How to make it.**

1. Cut four lengths of 300 with mitred ends and weld them into a square frame 300 x 300 outside.
2. Cut four legs 70 long and weld one under each corner; weld a 60 x 60 x 5 pad under each leg.
3. Check the grate sits flat on the frame.

**How it fits the parts next to it.**

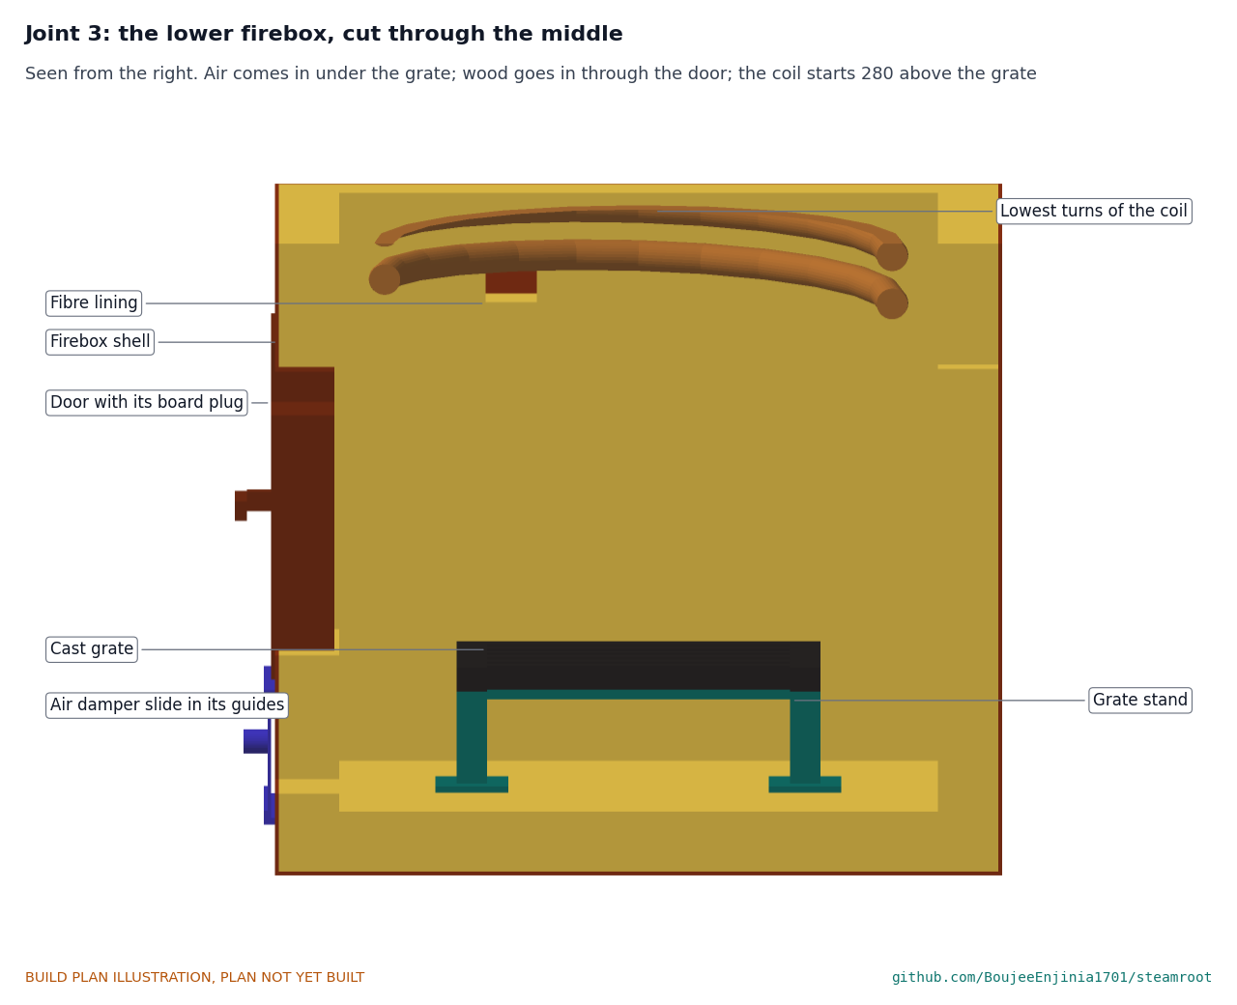
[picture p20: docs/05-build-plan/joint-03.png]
Figure 9. Joint 3: the lower firebox, cut through the middle


*Figure 9. The stand sits on the floor board in the middle of the firebox, under the coil. The air inlet opens into the ash pit under the grate; the door opening is level with the fire; the coil starts 280 above the grate.*

**Check before moving on.** The grate sits flat and does not rock; there is 280 from the top of the grate to the lowest turn of the coil.

### 3.7 Firebox door

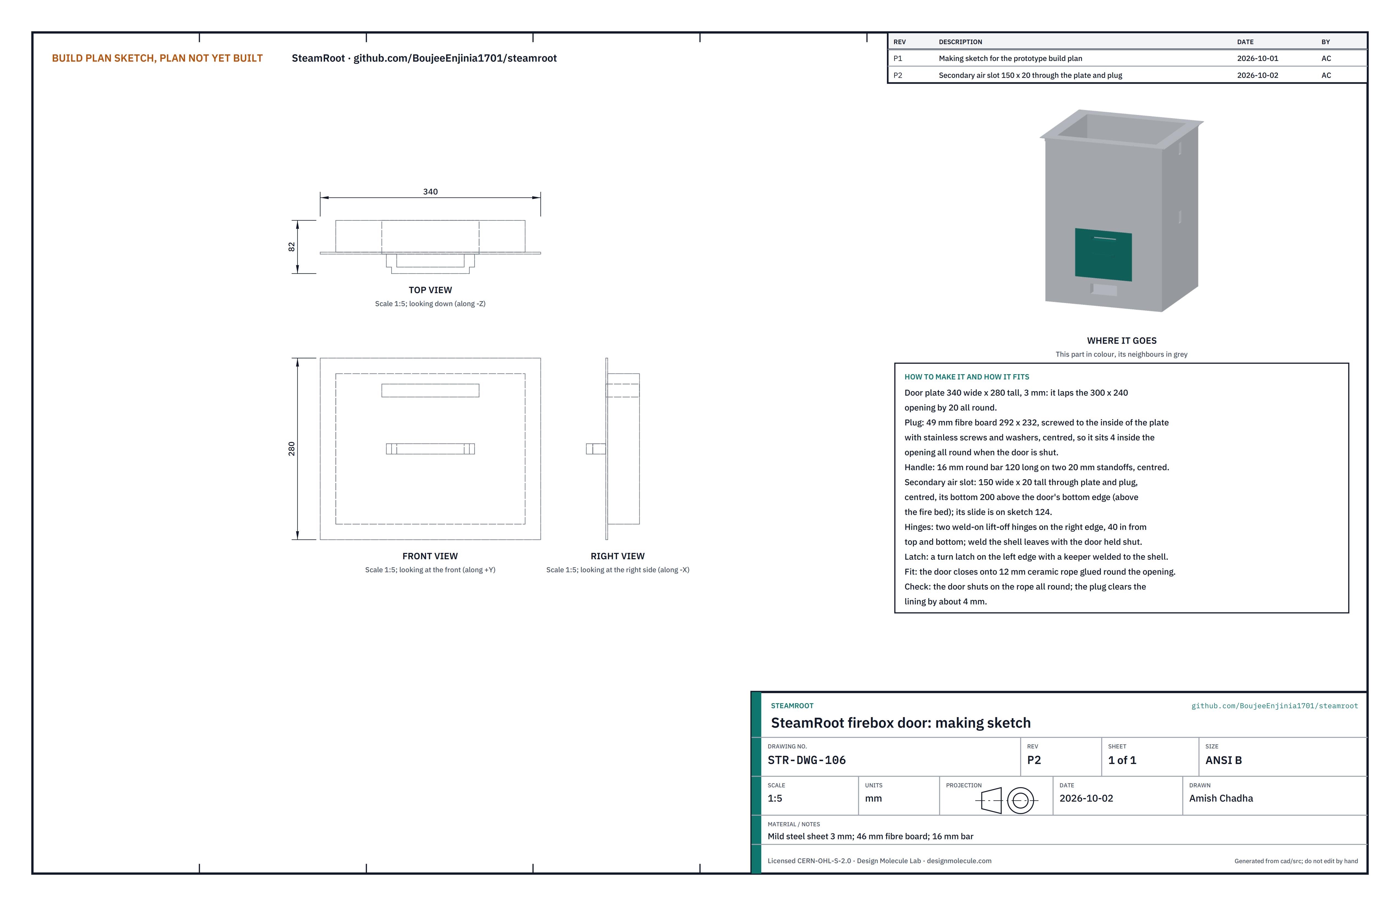
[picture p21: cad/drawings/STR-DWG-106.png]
Figure 10. Making sketch of the firebox door


*Figure 10. Firebox door making sketch (STR-DWG-106).*

**What it is and what it is made from.** The door wood is loaded through, with a fibre board plug that fills the opening in the lining. Mild steel sheet 3 mm, 49 mm fibre board, 16 mm round bar, two weld-on lift-off hinges and a turn latch.

**How to make it.**

1. Cut the door plate 340 wide x 280 tall; it laps the opening by 20 all round.
2. Cut the plug from fibre board, 292 x 232 x 49, and screw it to the inside of the plate, centred, with stainless screws and large washers. It sits 4 inside the opening all round.
3. Weld a 120 handle of 16 mm bar on two 20 mm standoffs, centred on the front.
4. Cut the secondary air slot, 150 wide x 20 tall, through the plate and the plug, centred, its bottom 200 above the bottom edge of the plate, so it opens above the fire bed. Its slide is in section 3.27.
5. Weld the door leaves of the two hinges to the right edge of the door, 40 in from top and bottom. Hold the door shut in place and weld the shell leaves to the shell.
6. Fit the turn latch on the left edge of the door and weld its keeper to the shell.
7. Glue 12 mm ceramic rope round the opening on the shell, where the door plate closes.

**How it fits the parts next to it.**

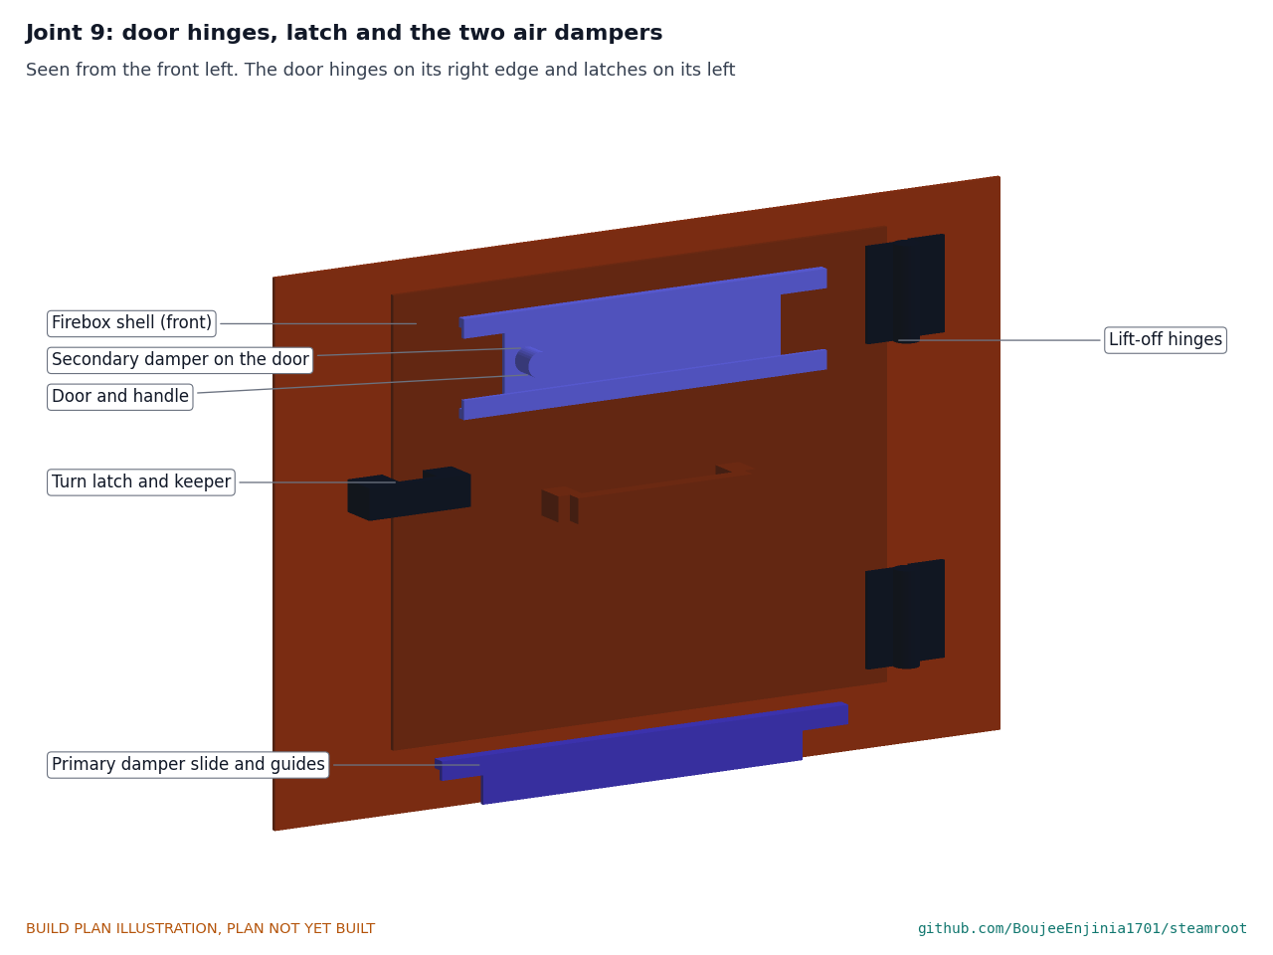
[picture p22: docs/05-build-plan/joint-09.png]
Figure 11. Joint 9: door hinges, latch and the two air dampers


*Figure 11. The door hinges on its right edge and latches on its left. Below it, the primary air damper slides sideways between its guides; the secondary damper slides on the door itself.*

**Check before moving on.** The door shuts on the rope all round and latches; the plug clears the lining by about 4.

### 3.8 Primary air damper slide and guides

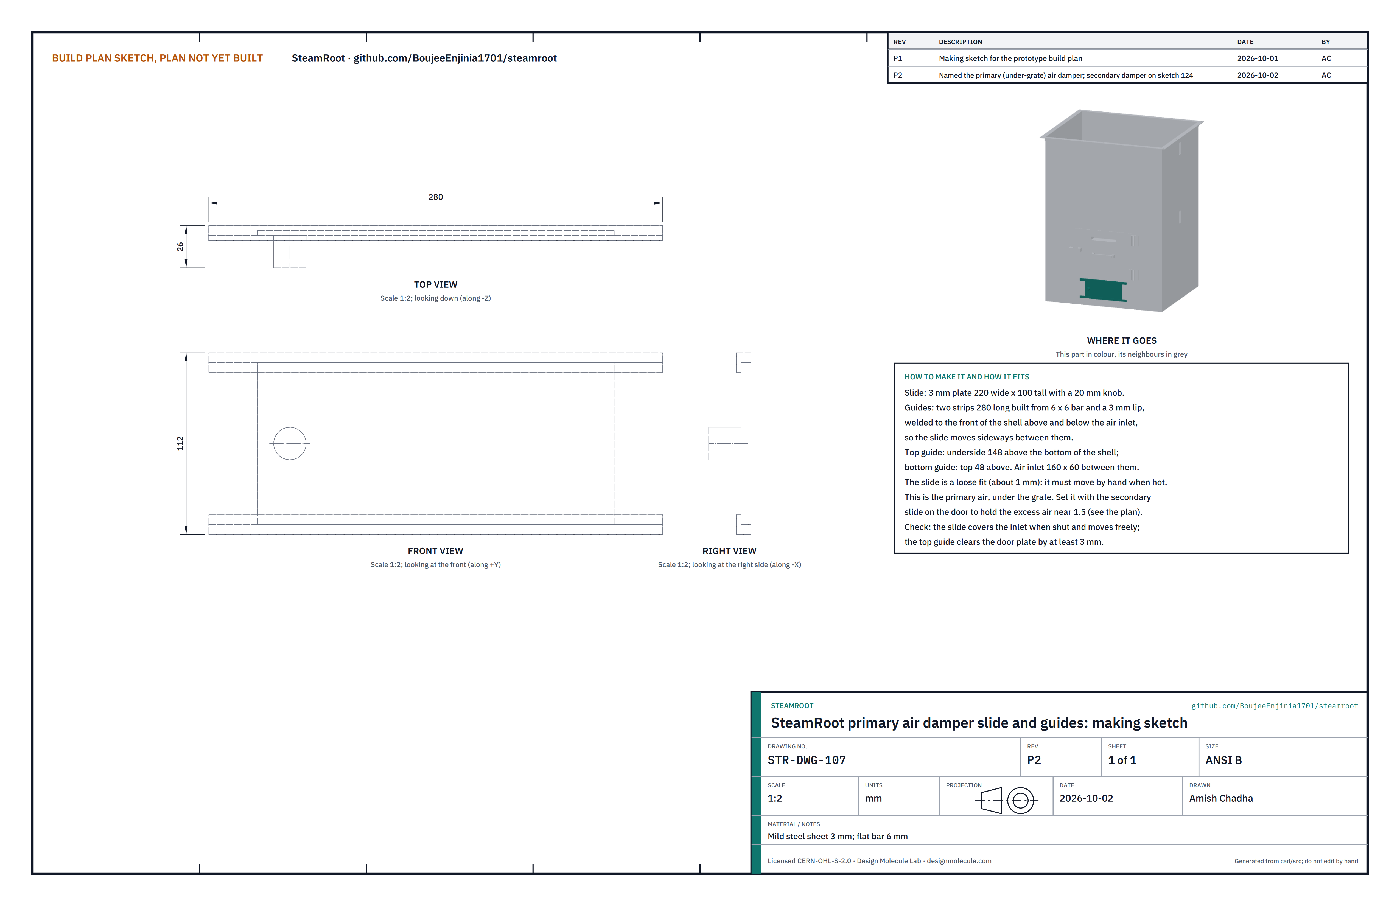
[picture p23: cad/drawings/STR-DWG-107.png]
Figure 12. Making sketch of the primary air damper


*Figure 12. Primary air damper slide and guides making sketch (STR-DWG-107).*

**What it is and what it is made from.** A plate that slides sideways over the air inlet under the grate to set how fast the fire burns. With the secondary damper on the door (section 3.27) it holds the excess air near 1.5, which the efficiency of section 3.25 depends on. Mild steel sheet 3 mm, 6 mm bar.

**How to make it.**

1. Cut the slide 220 wide x 100 tall from 3 mm sheet and weld a 20 mm knob near its left end.
2. Make two guides 280 long, each from a 6 x 6 bar welded to the shell and a 3 mm lip over it, so they form a channel the slide runs in.
3. Weld the guides to the front of the shell, centred on the air inlet: the top guide's underside 148 above the bottom of the shell, the bottom guide's top 48 above. Check the top guide clears the door plate by at least 3.

**How it fits the parts next to it.** The slide is a loose fit, about 1 mm, so it moves by hand when hot (Figure 11). Fully across, it shuts the air off.

**Check before moving on.** The slide covers the inlet when shut and moves freely.

### 3.9 Monotube coil

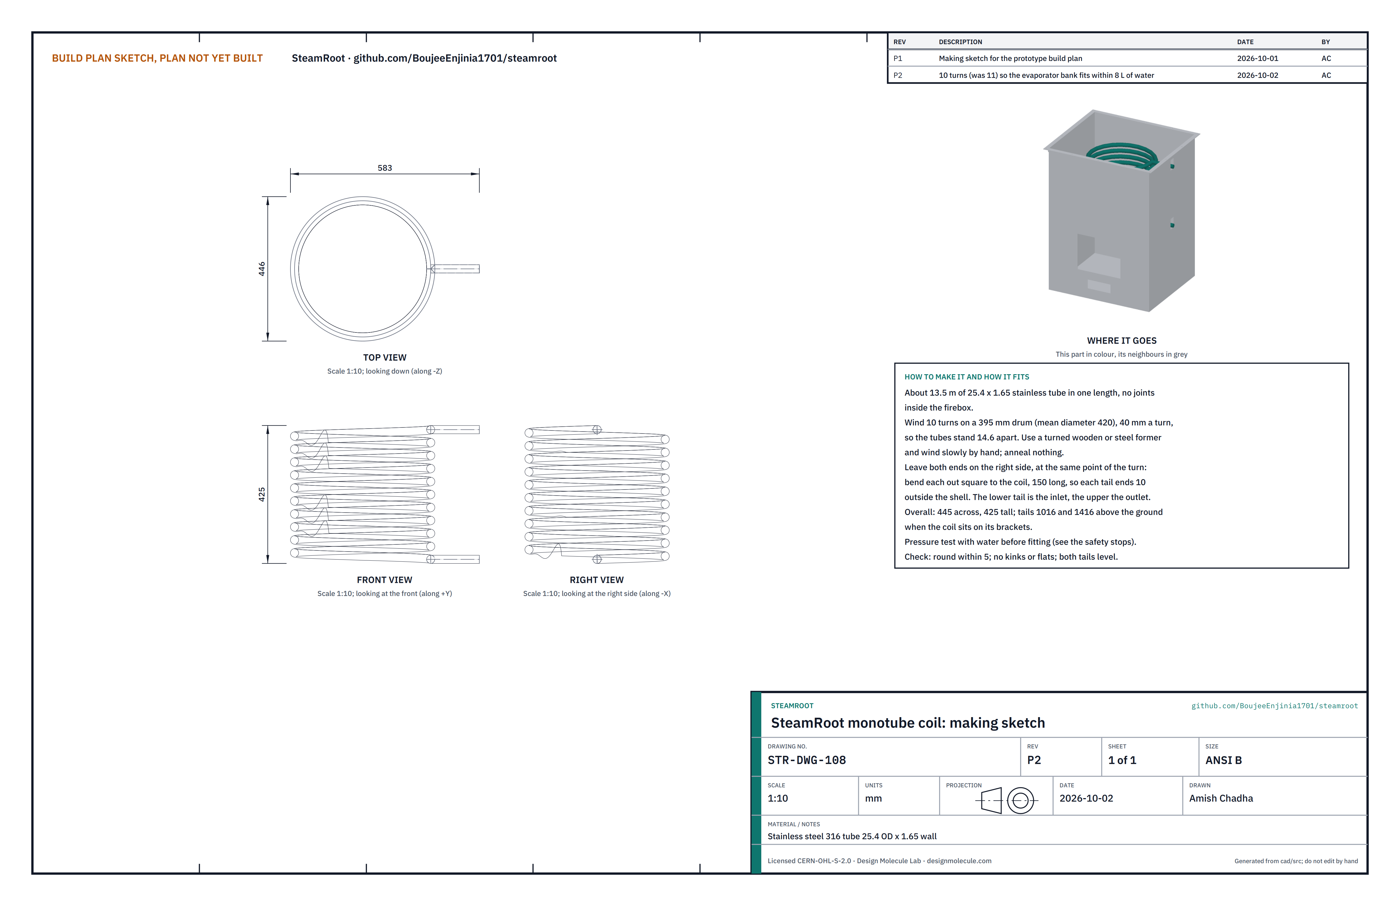
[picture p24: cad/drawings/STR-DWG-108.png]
Figure 13. Making sketch of the monotube coil


*Figure 13. Monotube coil making sketch (STR-DWG-108).*

**What it is and what it is made from.** The coil the water boils in, wound from one length of stainless steel 316 tube, 25.4 outside diameter, 1.65 wall, with no joint inside the firebox.

**How to make it.**

1. Make a former: a drum 395 in diameter and about 500 long, turned from timber or rolled from steel, with a slot to start the tube.
2. Leave 150 of straight tube at the start. Wind 10 turns by hand, slowly, keeping the turns 40 apart (14.6 between tubes) with spacer blocks. The mean diameter is 420.
3. Leave 150 of straight tube at the end. Bend each end out square to the coil on about a 75 radius, so both tails point the same way, one at the bottom and one at the top of the coil, and each ends 10 outside the shell when the coil is in place.
4. Slide the coil off the former. Check it is 445 across and 425 tall.
5. Fill it with water and pressure test it cold to 3 bar, the pump's shut-off pressure; hold 10 minutes with no fall and no leak.

**How it fits the parts next to it.** The coil rests on the three brackets (Figure 6). Its lower tail is the water inlet, 1016 above the ground; its upper tail is the steam outlet, 1416 above the ground. Both pass out through the slots in the right end (Figure 15).

**Check before moving on.** The coil is round within 5, with no kinks or flats, and both tails are level and parallel.

### 3.10 Tube gland plates (make 2)

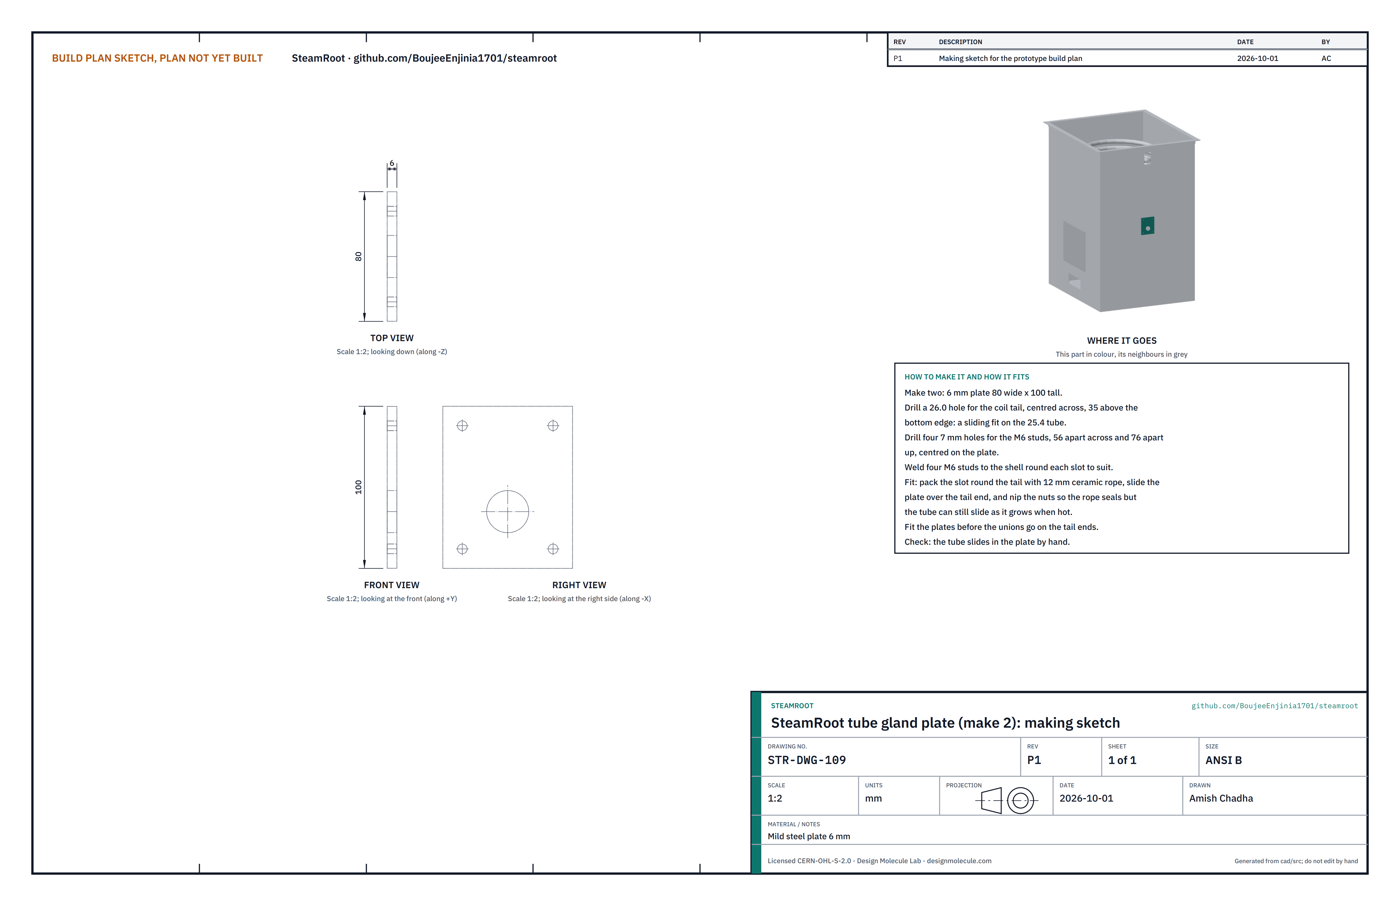
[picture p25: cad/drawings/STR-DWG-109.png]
Figure 14. Making sketch of the tube gland plate


*Figure 14. Tube gland plate making sketch (STR-DWG-109).*

**What it is and what it is made from.** A plate that closes each tube slot round a coil tail and holds the rope packing that seals it, while letting the tube slide as it grows. Mild steel plate 6 mm.

**How to make it.**

1. Cut two plates 80 wide x 100 tall.
2. Drill a 26.0 hole for the tail, centred across, 35 above the bottom edge.
3. Drill four 7 mm holes for the studs, 56 apart across and 76 apart up and down, centred on the plate. Mark the four M6 studs on the shell through these holes and weld them on (section 3.2).

**How it fits the parts next to it.**

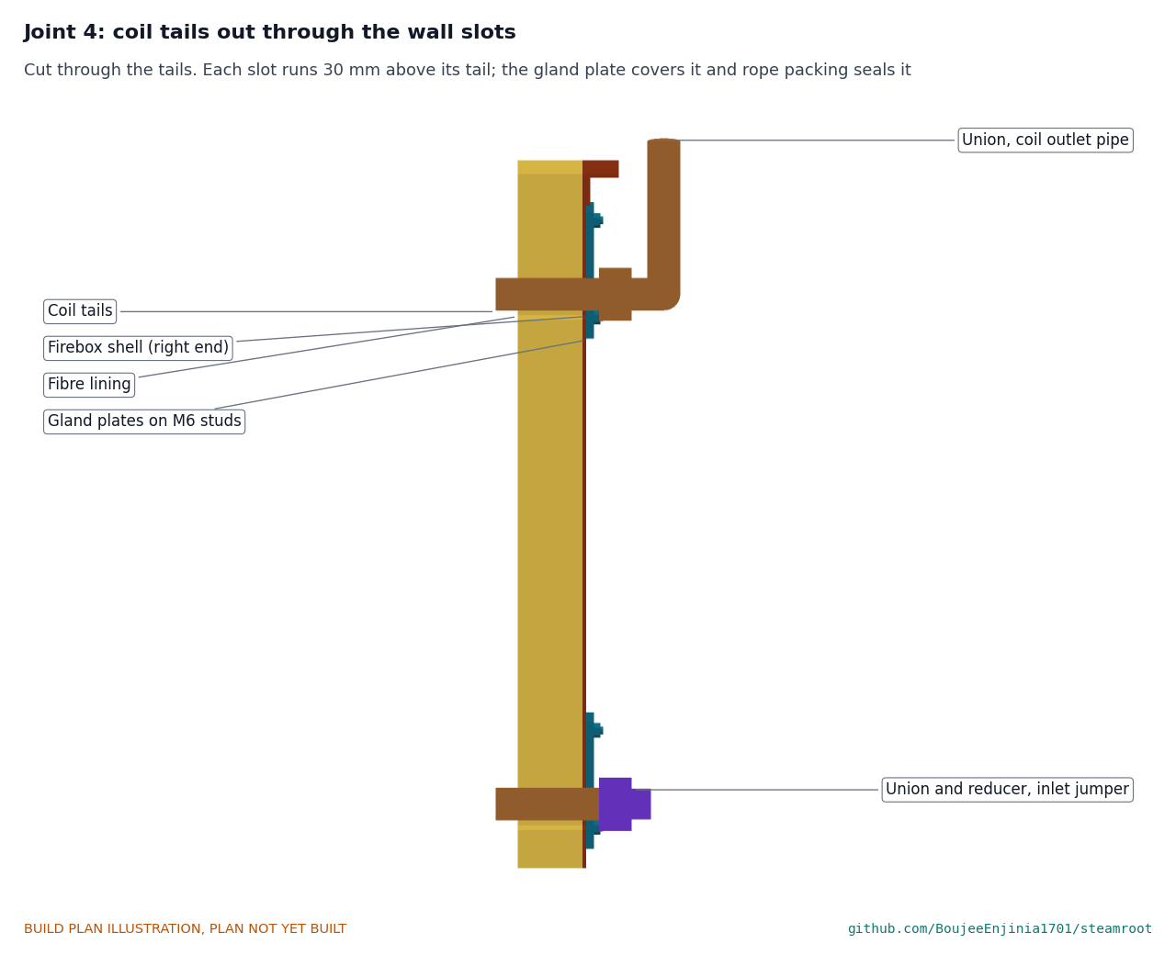
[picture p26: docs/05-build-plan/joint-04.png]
Figure 15. Joint 4: coil tails out through the wall slots


*Figure 15. Each slot runs 30 above its tail so the coil can go in high. Pack the slot round the tail with 12 mm ceramic rope, slide the plate over the tail end and nip the nuts. The unions go on afterwards.*

**Check before moving on.** Each tail slides in its plate by hand.

### 3.11 Firebox roof and roof board

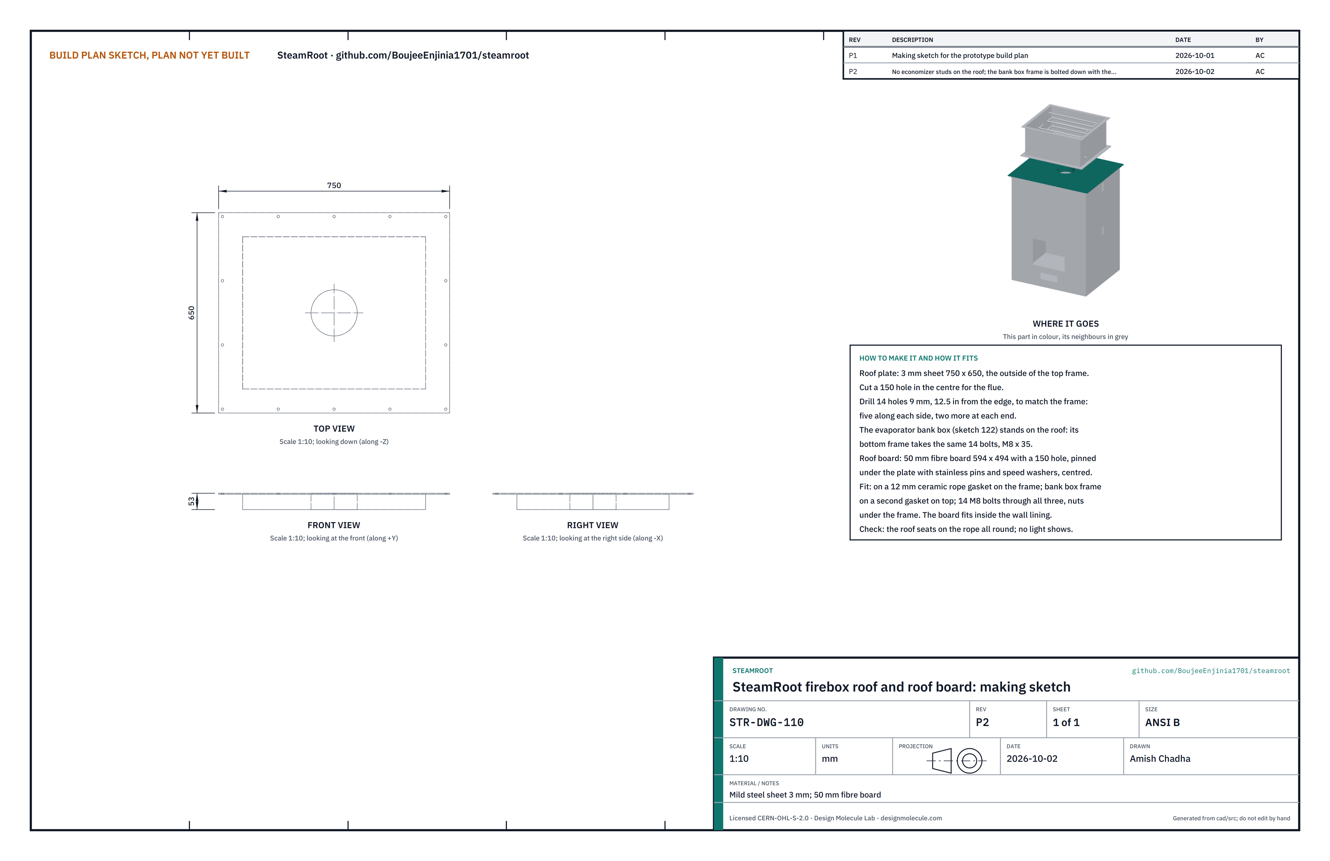
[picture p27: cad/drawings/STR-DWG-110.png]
Figure 16. Making sketch of the firebox roof


*Figure 16. Firebox roof making sketch (STR-DWG-110).*

**What it is and what it is made from.** The bolted lid of the firebox, lined underneath, which carries the evaporator bank box and, on that, the economizer. Mild steel sheet 3 mm and 50 mm fibre board.

**How to make it.**

1. Cut the plate 750 x 650 and a 150 hole in its centre.
2. Drill 14 holes of 9 mm to match the top frame (clamp the plate to the frame and drill through).
3. Pin the roof board (section 3.5) centred under the plate with stainless pins and speed washers, lining up the two 150 holes.

**How it fits the parts next to it.** It sits on a 12 mm ceramic rope gasket on the top frame. The bank box frame sits on a second gasket on top of it, and 14 M8 x 35 bolts clamp the bank box frame, the roof and the top frame together, nuts under the frame; the board fits inside the tops of the wall lining (Figure 18).

**Check before moving on.** The roof seats on the rope all round and no light shows between them.

### 3.12 Economizer box

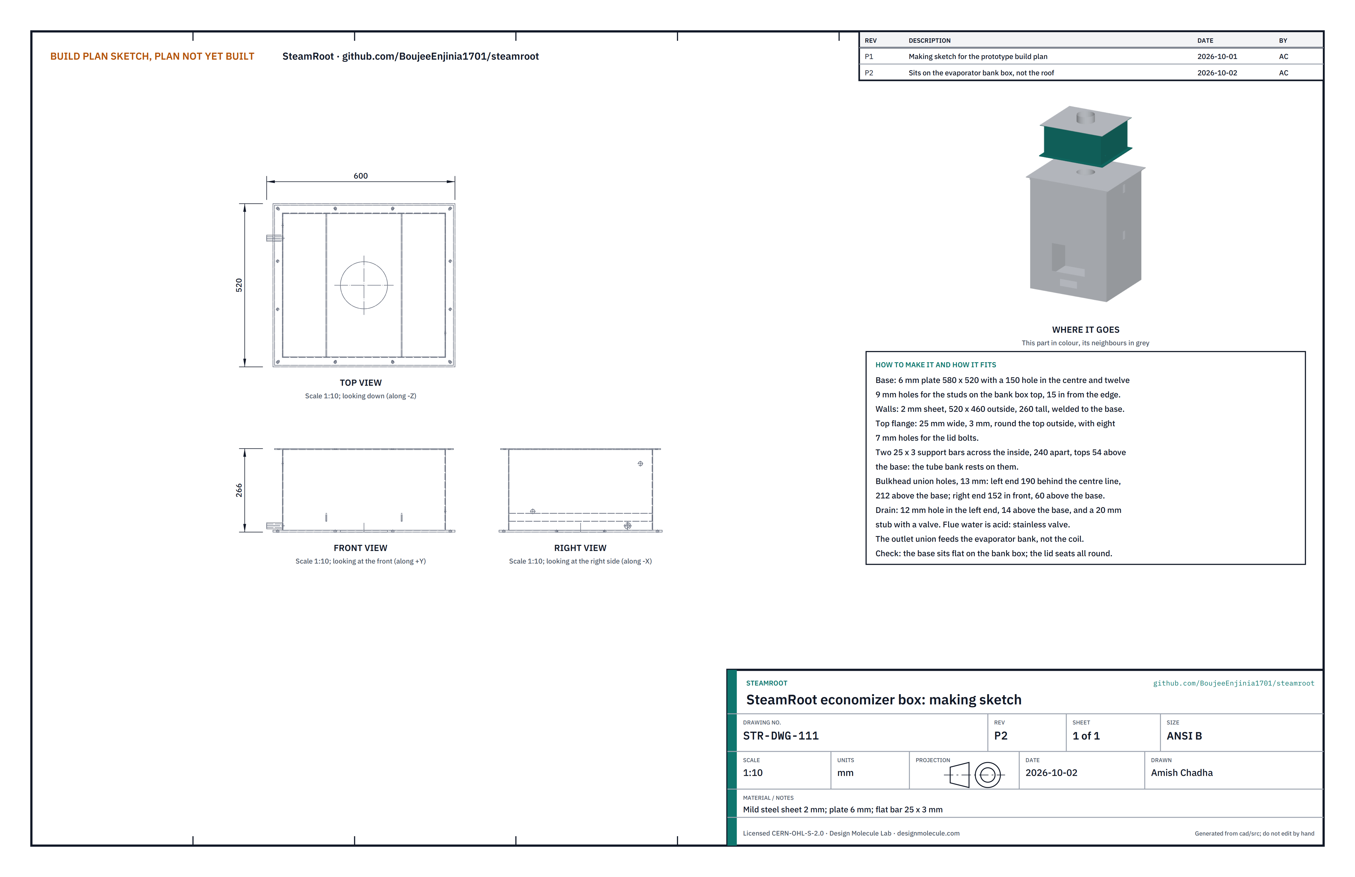
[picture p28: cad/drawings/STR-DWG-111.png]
Figure 17. Making sketch of the economizer box


*Figure 17. Economizer box making sketch (STR-DWG-111).*

**What it is and what it is made from.** The box above the firebox that the hot flue gas rises through, around the tube bank that warms the feed water. Mild steel sheet 2 mm, 6 mm plate and 25 x 3 mm flat bar.

**How to make it.**

1. Cut the base 580 x 520 from 6 mm plate, with a 150 hole in the centre and twelve 9 mm holes 15 in from the edge for the roof studs.
2. Cut and weld the walls from 2 mm sheet, 520 x 460 outside and 260 tall, onto the base. Weld a 25 wide, 3 mm flange round the top outside, with eight 7 mm holes for the lid bolts.
3. Weld two 25 x 3 support bars across the inside, 240 apart, their tops 54 above the base.
4. Drill the two 13 mm holes for the bulkhead unions: in the left end 190 behind the centre line and 212 above the base; in the right end 152 in front and 60 above the base. Fit the unions.
5. Drill a 12 mm drain hole in the left end, 14 above the base, 150 behind the centre line, and fit a stainless drain valve. The condensate is acid.

**How it fits the parts next to it.**

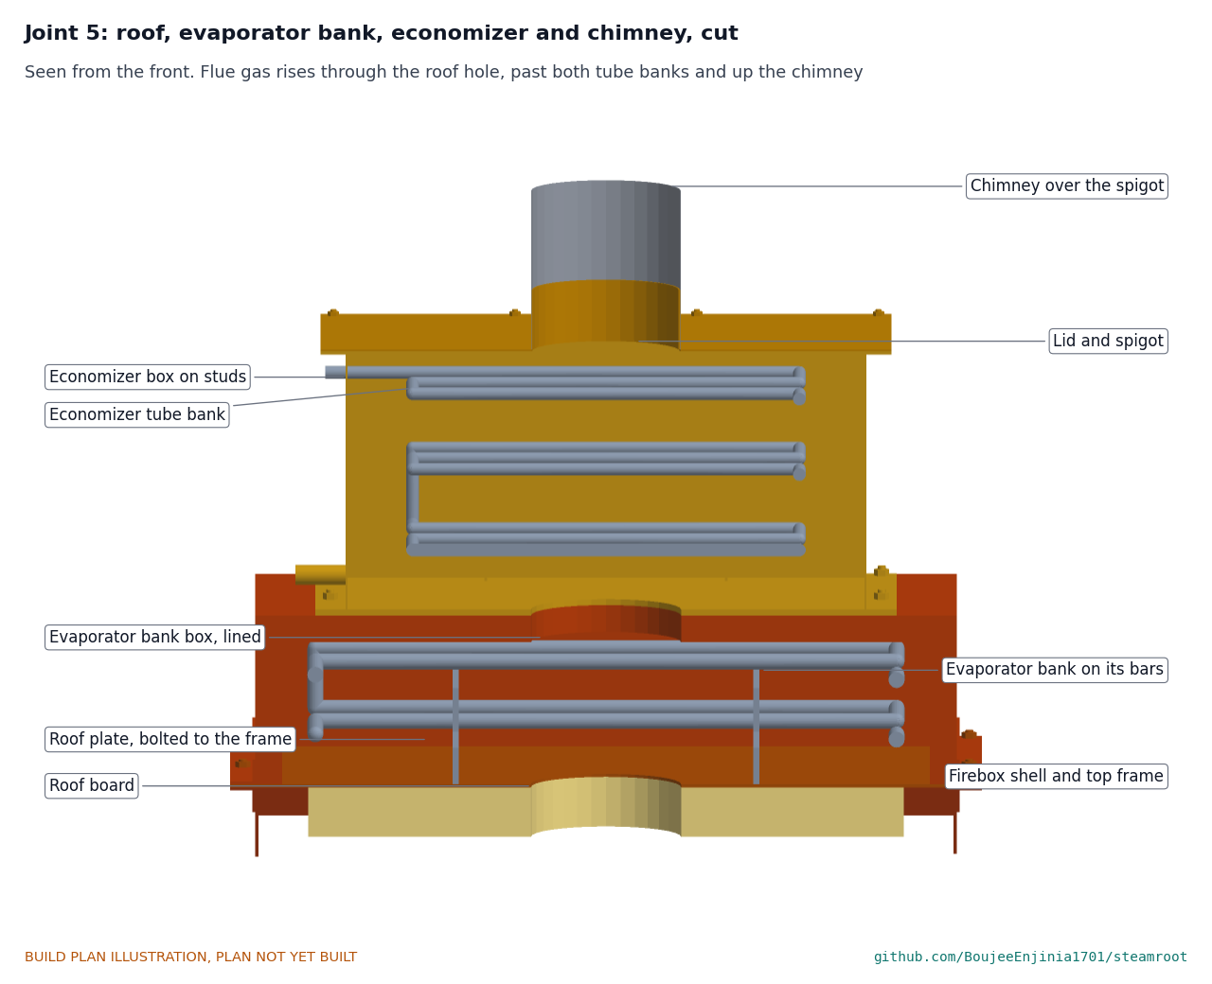
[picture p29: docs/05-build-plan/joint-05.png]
Figure 18. Joint 5: roof, evaporator bank, economizer and chimney, cut through the middle


*Figure 18. Roof, economizer and chimney cut through the middle. The economizer base now sits on the evaporator bank box (section 3.25), over the twelve studs on its top plate, nuts on top. Flue gas rises through the roof hole, past the evaporator bank, through the economizer tube bank and up the chimney.*

**Check before moving on.** The base sits flat on the bank box; the support bars are level.

### 3.13 Economizer tube bank

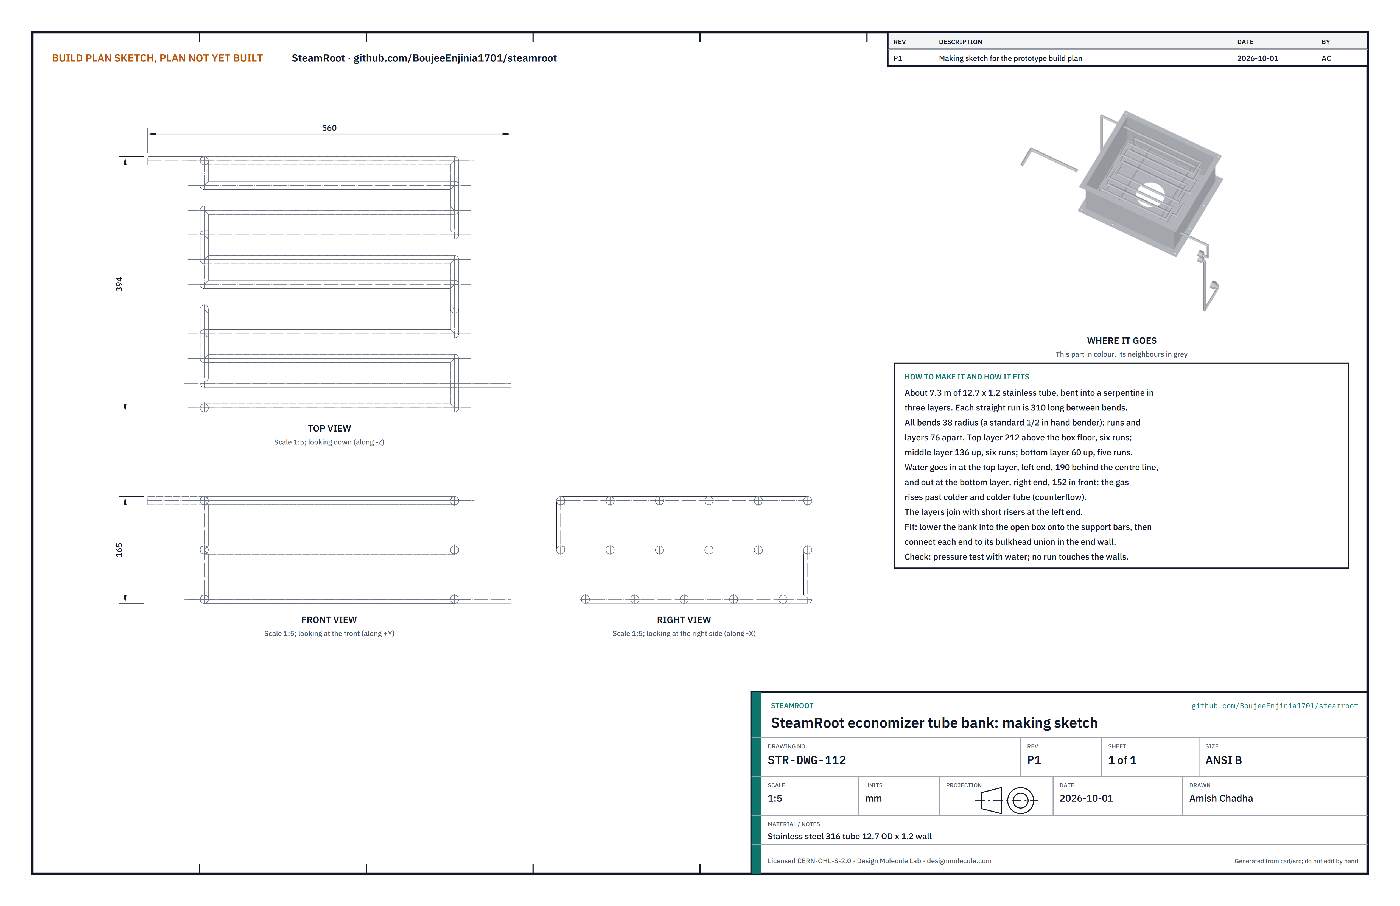
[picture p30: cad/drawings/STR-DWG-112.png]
Figure 19. Making sketch of the economizer tube bank


*Figure 19. Economizer tube bank making sketch (STR-DWG-112).*

**What it is and what it is made from.** The serpentine of stainless tube inside the economizer that the feed water flows through. About 7.3 m of stainless steel 316 tube, 12.7 outside diameter, 1.2 wall.

**How to make it.**

1. Bend the tube with a standard 1/2 in hand bender (38 radius), so the straight runs are 76 apart and each is 310 long between bends.
2. Top layer, 212 above the box floor: six runs, starting at the left end 190 behind the centre line. Turn down at the left end to the middle layer, 136 above the floor: six runs. Turn down again to the bottom layer, 60 above the floor: five runs, ending at the right end 152 in front of the centre line.
3. Leave a short straight at each end to meet the bulkhead unions.
4. Pressure test it cold to 3 bar for 10 minutes.

**How it fits the parts next to it.** Lower it into the open box onto the two support bars, then connect each end to its bulkhead union (step 10). Water enters at the top and leaves at the bottom, so the rising gas meets colder and colder tube.

**Check before moving on.** No run touches a wall; no leak at 3 bar.

### 3.14 Economizer lid

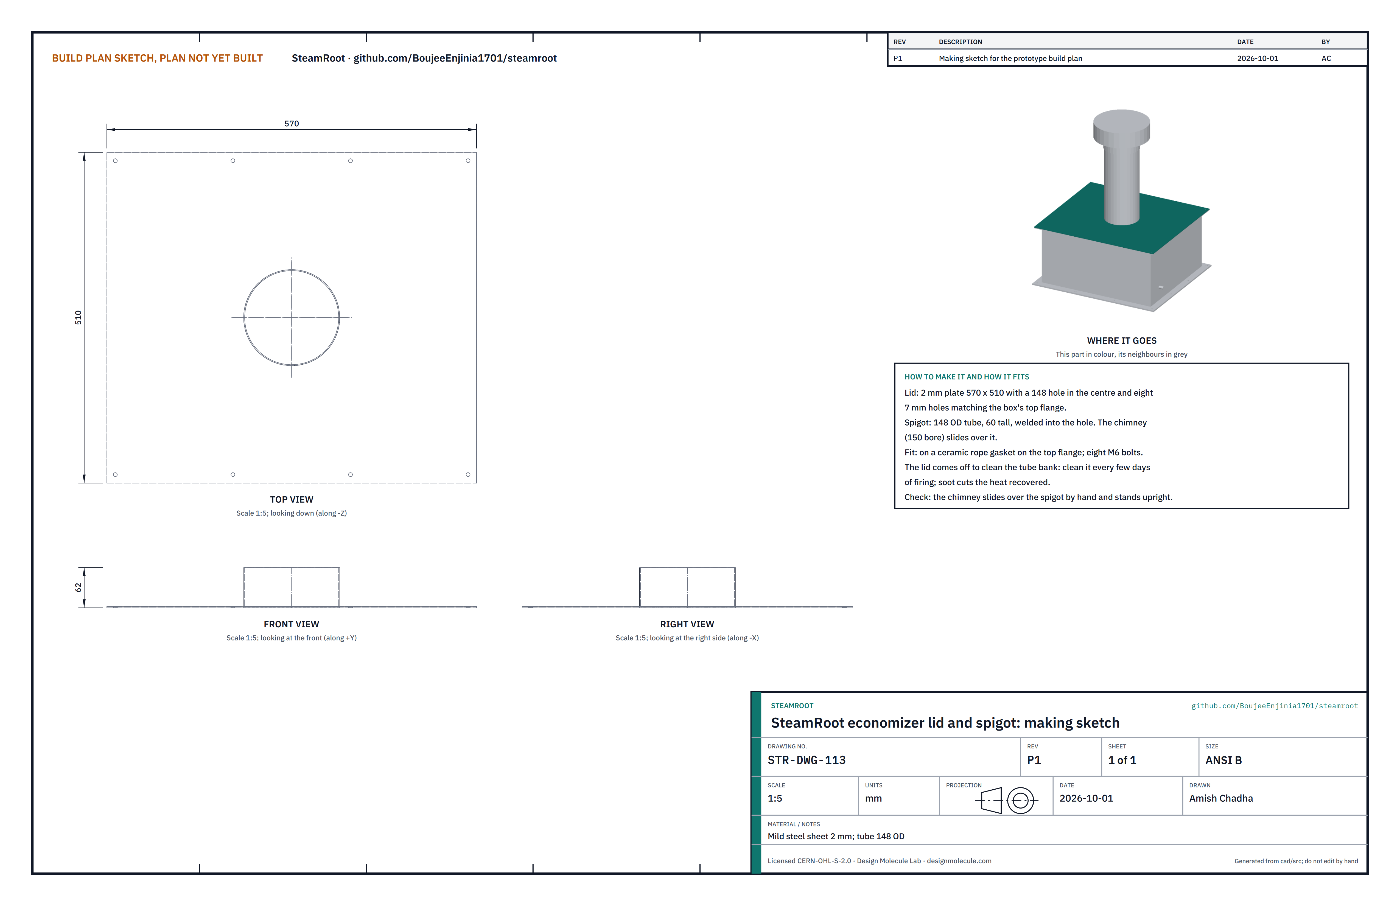
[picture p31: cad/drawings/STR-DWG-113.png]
Figure 20. Making sketch of the economizer lid


*Figure 20. Economizer lid and spigot making sketch (STR-DWG-113).*

**What it is and what it is made from.** The bolted top of the economizer, carrying the spigot the chimney stands on. Mild steel sheet 2 mm and a short length of 148 mm tube.

**How to make it.**

1. Cut the lid 570 x 510 with a 148 hole in the centre and eight 7 mm holes matching the box's top flange.
2. Weld a 148 outside diameter tube, 60 tall, upright into the hole.

**How it fits the parts next to it.** The lid sits on a rope gasket on the top flange under eight M6 bolts; the chimney (150 bore) slides over the spigot (Figure 18). Take the lid off to brush soot from the tube bank.

**Check before moving on.** The chimney slides over the spigot by hand and stands upright.

### 3.15 Header post

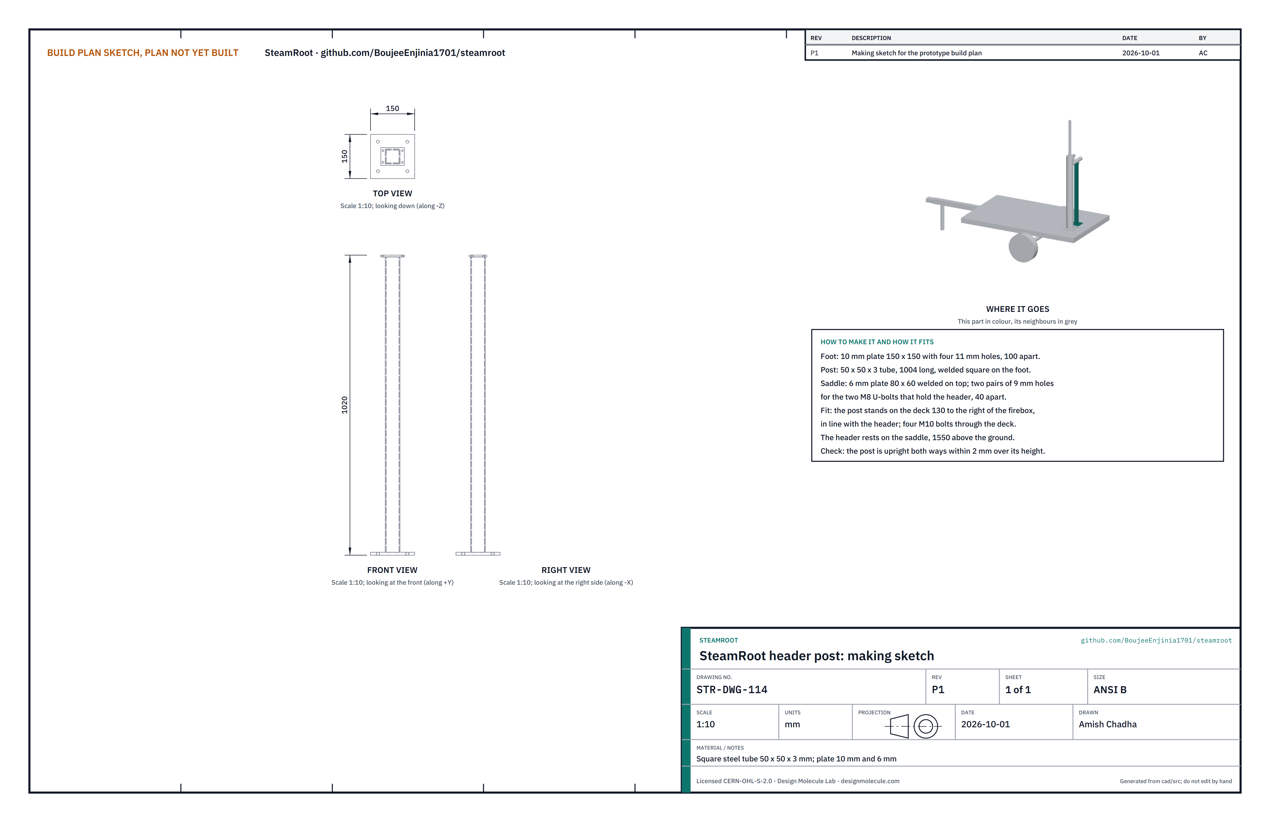
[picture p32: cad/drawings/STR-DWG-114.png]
Figure 21. Making sketch of the header post


*Figure 21. Header post making sketch (STR-DWG-114).*

**What it is and what it is made from.** The post that carries the steam header 1550 above the ground. Square steel tube 50 x 50 x 3 mm, 10 mm and 6 mm plate, two M8 U-bolts.

**How to make it.**

1. Cut the foot 150 x 150 from 10 mm plate and drill four 11 mm holes 100 apart.
2. Cut the post 1004 long and weld it square on the centre of the foot.
3. Weld a 6 mm saddle plate 80 x 60 on top and drill two pairs of 9 mm holes for the U-bolts, 40 apart.

**How it fits the parts next to it.**

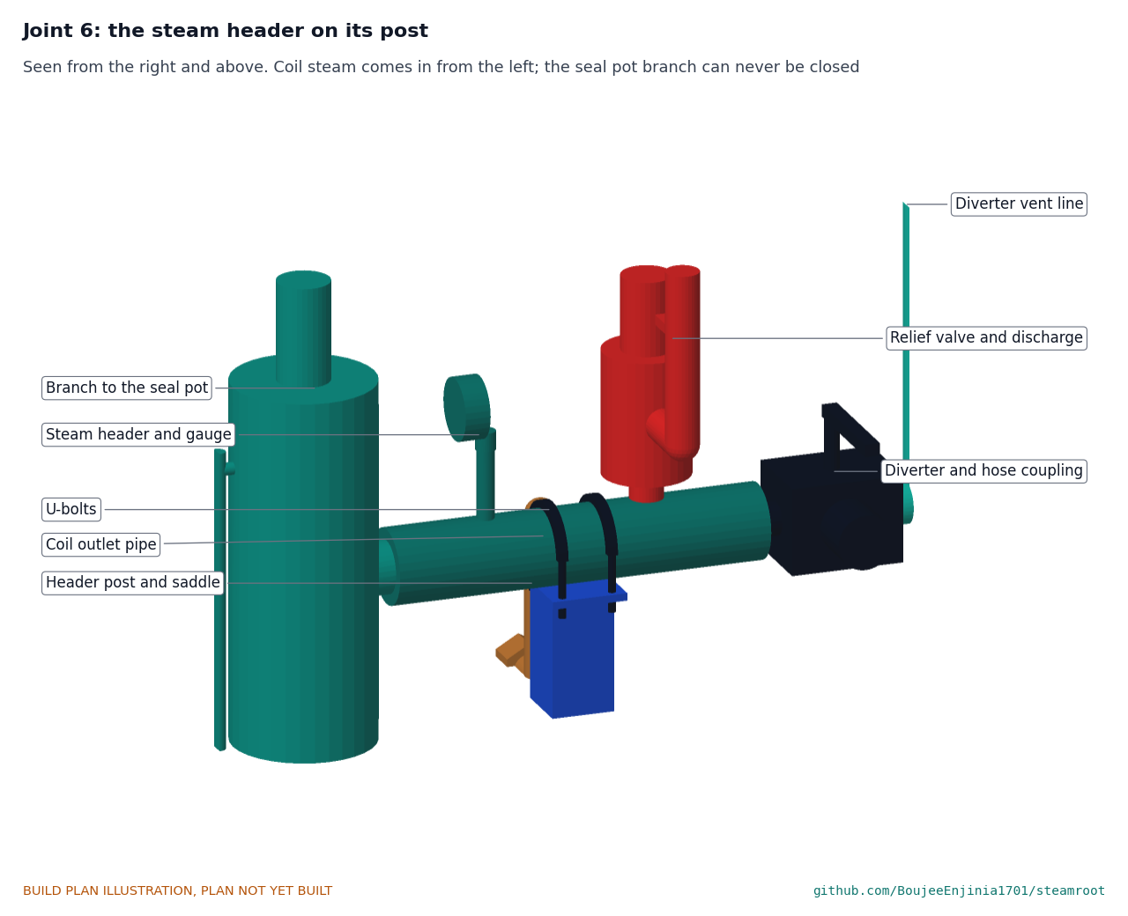
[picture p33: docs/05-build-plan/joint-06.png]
Figure 22. Joint 6: the steam header on its post


*Figure 22. The header lies on the saddle under two U-bolts. The coil outlet pipe enters its left side, the seal pot branch leaves its front end, the diverter its back end; the relief valve and gauge stand on top.*

The post stands on the deck 130 to the right of the firebox, on the centre line, held by four M10 bolts through the deck.

**Check before moving on.** The post is upright both ways within 2 over its height.

### 3.16 Steam header

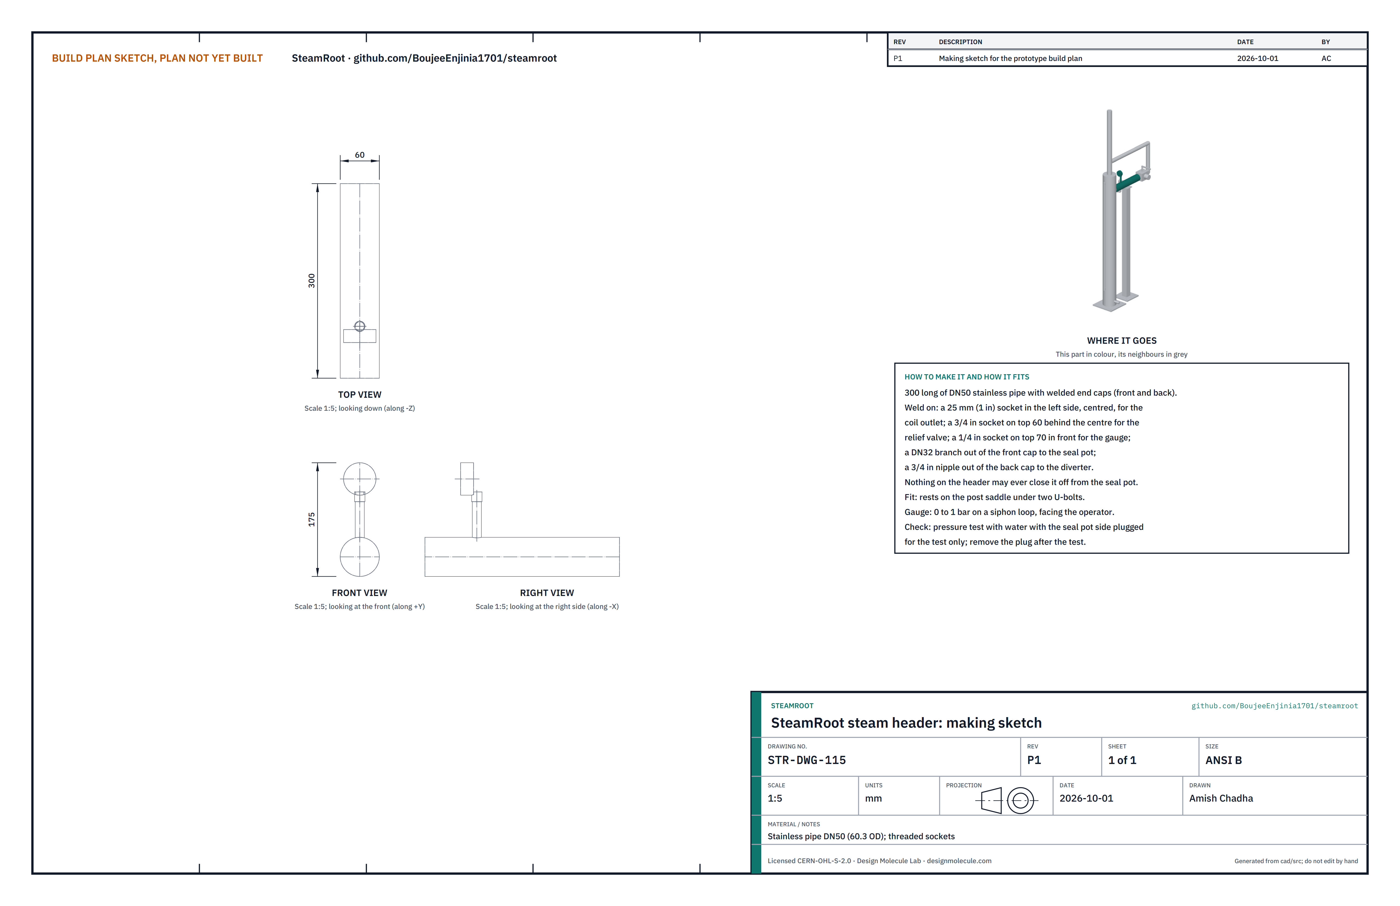
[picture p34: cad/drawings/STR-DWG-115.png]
Figure 23. Making sketch of the steam header


*Figure 23. Steam header making sketch (STR-DWG-115).*

**What it is and what it is made from.** A short, wide pipe that collects the steam from the coil and passes it to the seal pot, the relief valve, the gauge and the diverter. Stainless steel pipe DN50 (60.3 outside diameter), 300 long, with welded caps and sockets.

**How to make it.**

1. Cut 300 of DN50 pipe and weld a cap on each end.
2. Weld on: a 1 in socket in the left side, centred, for the coil outlet; a 3/4 in socket on top 60 behind the centre for the relief valve; a 1/4 in socket on top 70 in front of the centre for the gauge; a DN32 branch out of the front cap toward the seal pot; a 3/4 in nipple out of the back cap for the diverter.
3. Fit the gauge (0 to 1 bar) on a siphon loop, facing the front.

**How it fits the parts next to it.** See Figure 22. Nothing fitted to the header may ever close it off from the seal pot.

**Check before moving on.** Pressure test it cold to 3 bar with the seal pot branch plugged for the test only; remove the plug at once afterwards.

### 3.17 Water-seal pot, dip leg and vent

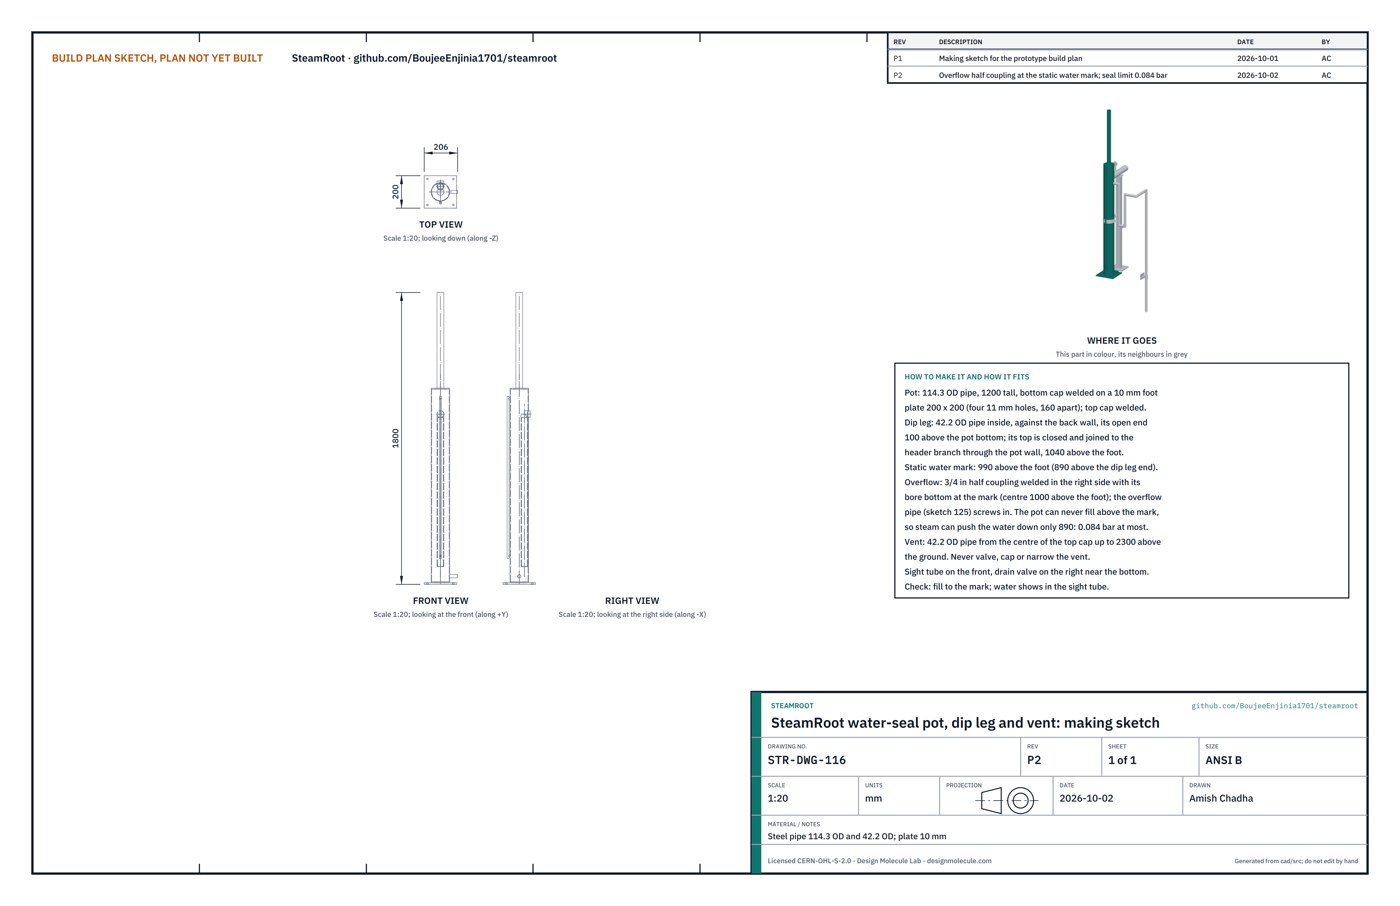
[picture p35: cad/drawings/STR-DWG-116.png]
Figure 24. Making sketch of the water-seal pot


*Figure 24. Water-seal pot, dip leg and vent making sketch (STR-DWG-116).*

**What it is and what it is made from.** The pot of water that limits the steam pressure: steam from the header goes down a dip leg under the water, and if the pressure ever passes 0.084 bar it pushes the water out of the way and escapes up the vent. An overflow at the water mark keeps the pot from being overfilled, so the limit can never rise above that. Steel pipe 114.3 and 42.2 outside diameter, 10 mm plate, a 3/4 in half coupling.

**How to make it.**

1. Cut the pot 1200 long from 114.3 pipe; weld a cap on the bottom and stand it on a 10 mm foot plate 200 x 200 with four 11 mm holes 160 apart.
2. Cut the dip leg from 42.2 pipe, open at the bottom and closed at the top. Fit it inside the pot against the back wall, its open end 100 above the pot bottom, and join its top through the pot wall to the header branch, 1040 above the foot plate.
3. Weld the top cap on, and the vent pipe (42.2) up from its centre to 2300 above the ground.
4. Fit a level sight tube on the front, with the static water mark 990 above the foot plate (890 above the dip leg's open end), and a drain valve on the right near the bottom.
5. Weld a 3/4 in half coupling into the right side of the pot with the bottom of its bore at the water mark (its centre 1000 above the foot plate). The overflow pipe (section 3.28) screws into it.

**How it fits the parts next to it.**

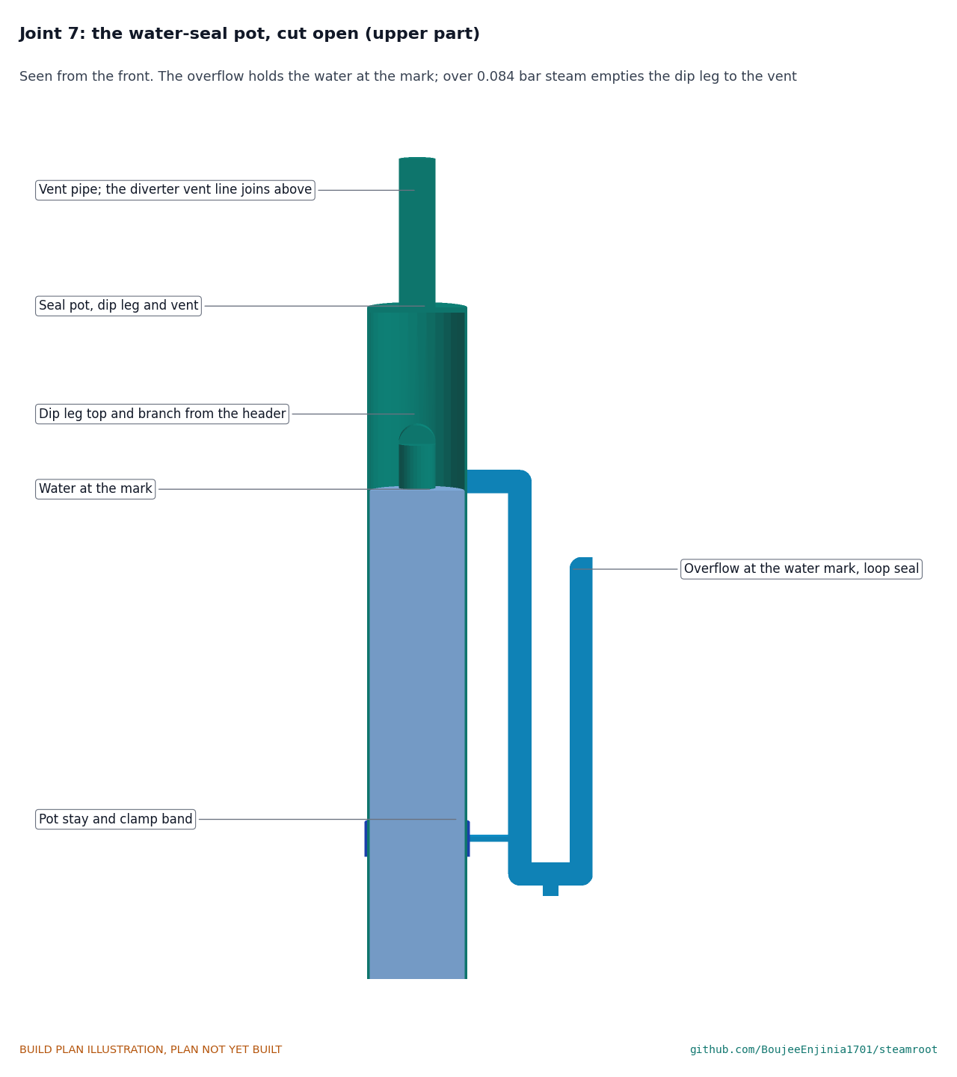
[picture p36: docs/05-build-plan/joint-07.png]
Figure 25. Joint 7: the water-seal pot, cut open


*Figure 25. The overflow holds the water at the mark: water pushed out of the dip leg runs away down the overflow instead of rising round it. So steam can push the water only 890 down the dip leg, 0.084 bar, before it bubbles through and leaves by the vent. The overflow's loop seal stops steam leaving that way. The diverter's vent line joins the vent above the pot.*

The pot stands on the deck in front of the header post, held by four M10 bolts and by the stay (section 3.18).

**Check before moving on.** Filled above the mark, the extra water runs out of the overflow at the ground and the level settles at the mark in the sight tube; the vent is open from end to end.

### 3.18 Pot stay

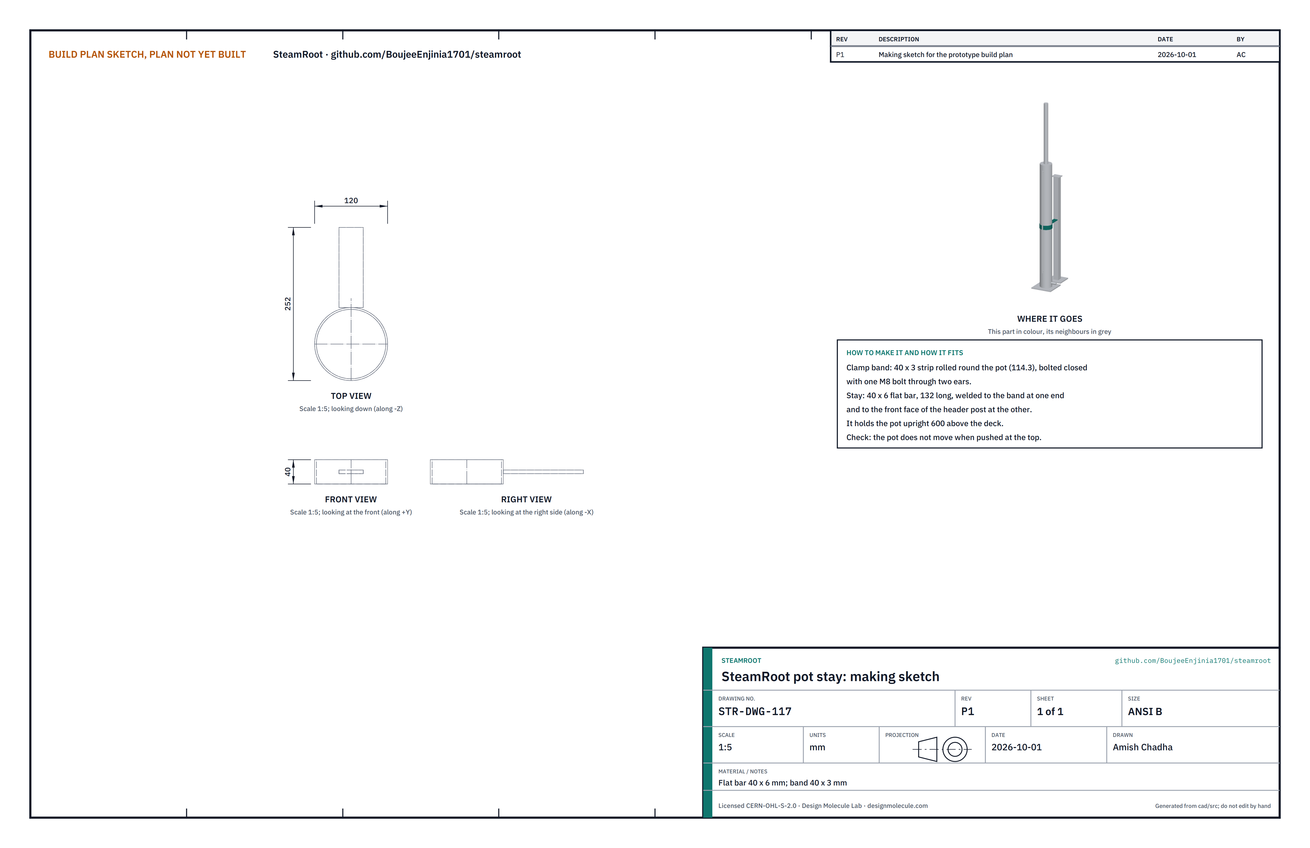
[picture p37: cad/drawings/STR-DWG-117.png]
Figure 26. Making sketch of the pot stay


*Figure 26. Pot stay making sketch (STR-DWG-117).*

**What it is and what it is made from.** A short bar that ties the tall seal pot to the header post. Flat bar 40 x 6 mm and a 40 x 3 mm band.

**How to make it.**

1. Roll a 40 x 3 band round a piece of 114.3 pipe, with two ears for an M8 bolt.
2. Cut the stay 132 long from 40 x 6 bar and weld it to the band.

**How it fits the parts next to it.** Bolt the band round the pot 600 above the deck and weld the other end of the stay to the front of the post (Figure 22).

**Check before moving on.** The pot does not move when pushed at the top.

### 3.19 Drum saddles (make 2)

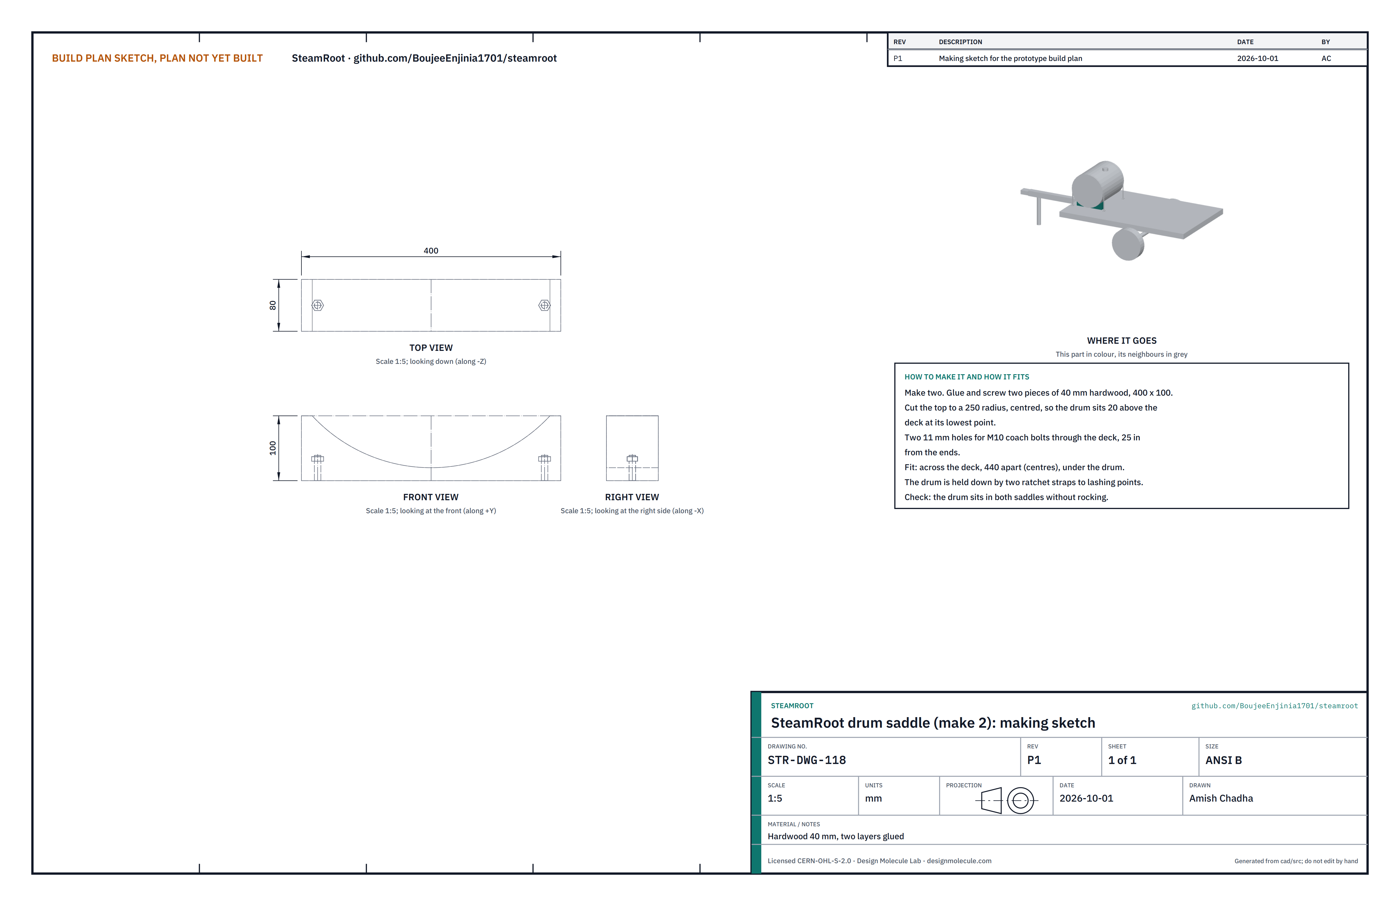
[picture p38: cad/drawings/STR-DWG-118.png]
Figure 27. Making sketch of the drum saddle


*Figure 27. Drum saddle making sketch (STR-DWG-118).*

**What it is and what it is made from.** Two curved blocks the feed drum lies in. Hardwood 40 mm, two layers glued and screwed.

**How to make it.**

1. Glue and screw two pieces of 40 mm hardwood, 400 x 100, for each saddle.
2. Cut the top to a 250 radius, centred, so the drum sits 20 above the deck at its lowest point.
3. Drill two 11 mm holes 25 in from the ends for M10 coach bolts.

**How it fits the parts next to it.**

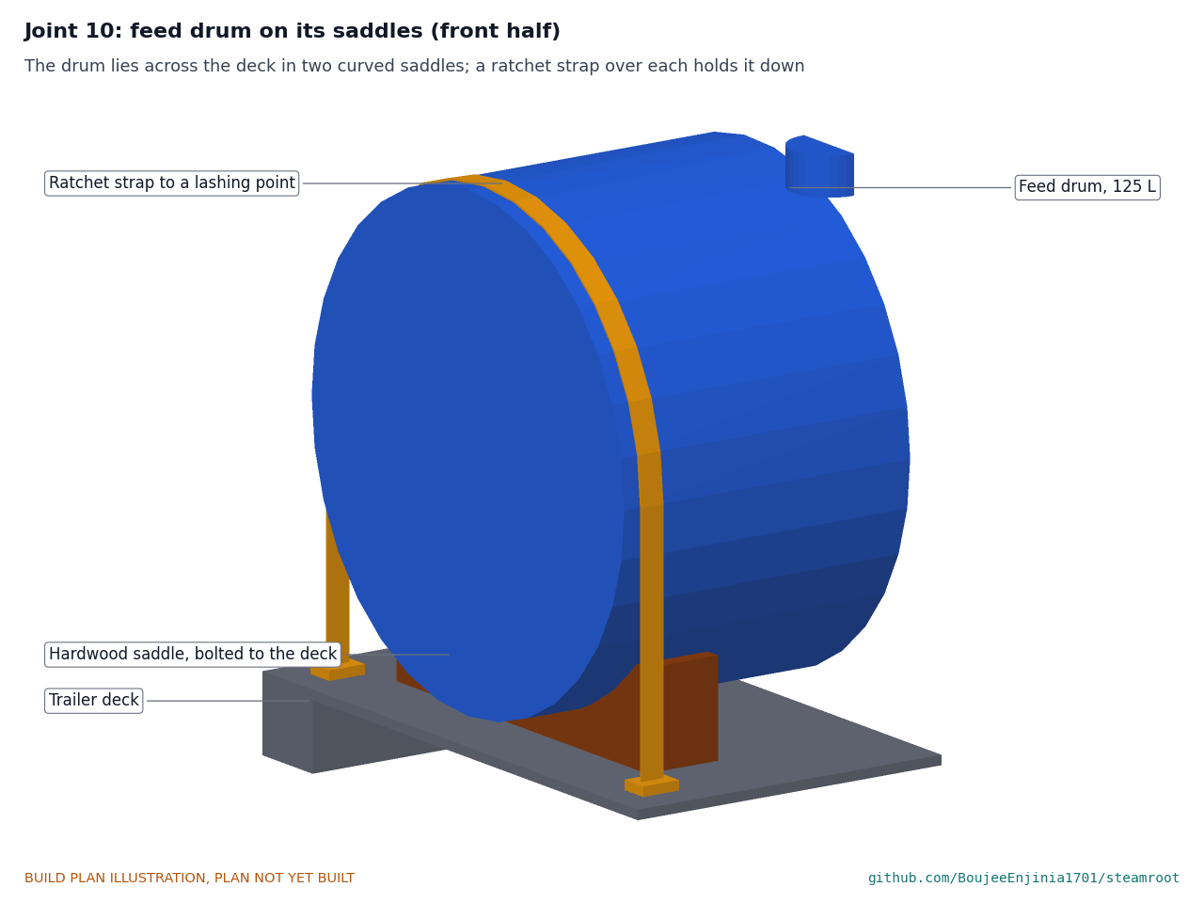
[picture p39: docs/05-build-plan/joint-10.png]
Figure 28. Joint 10: feed drum on its saddles


*Figure 28. The drum lies across the deck in the two saddles, 440 apart, held down by a ratchet strap over each to lashing points on the deck.*

**Check before moving on.** The drum sits in both saddles without rocking.

### 3.20 Hood shells (make 2)

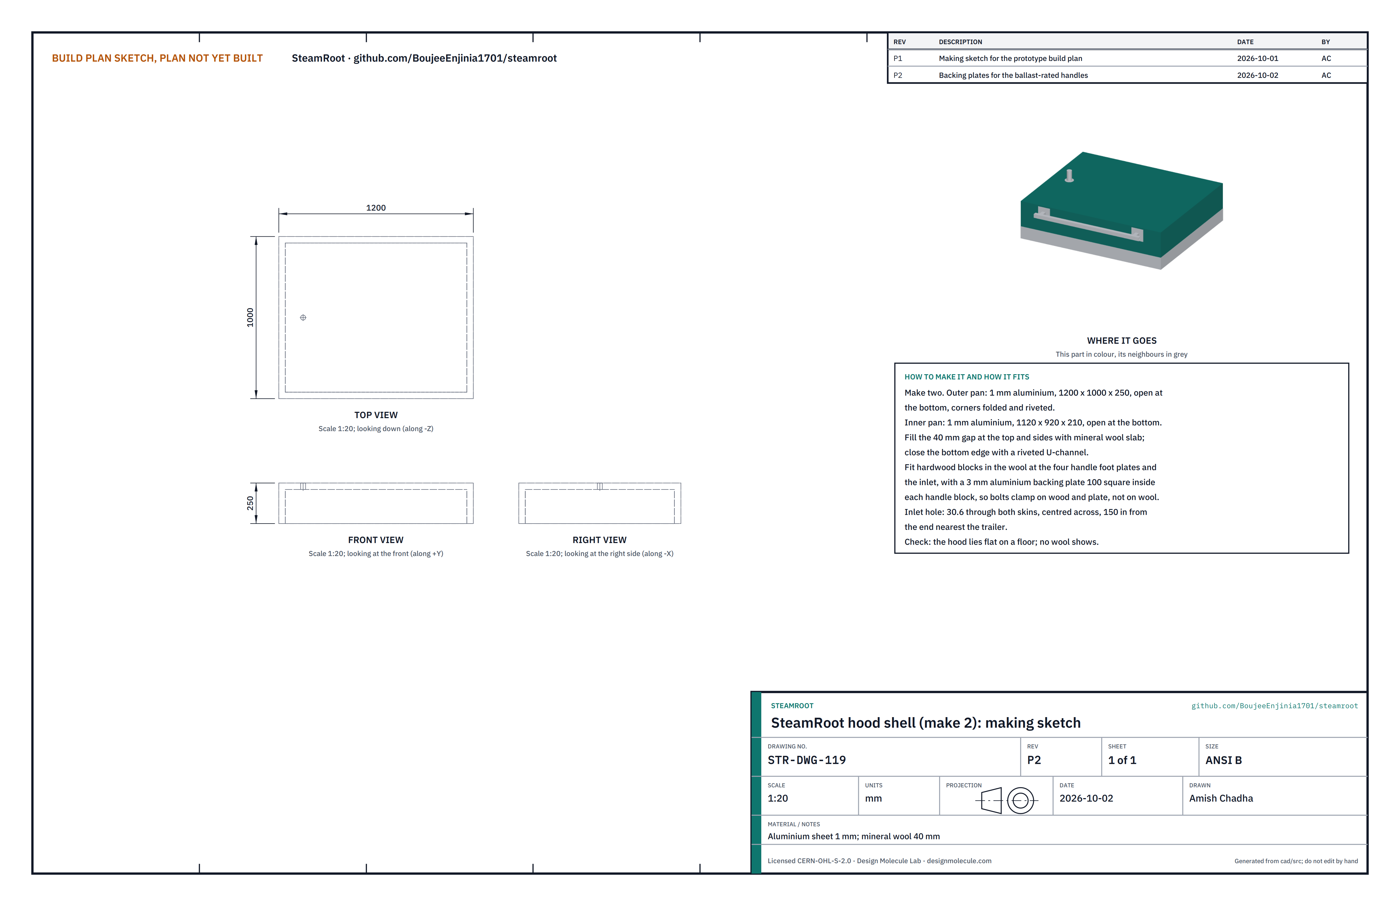
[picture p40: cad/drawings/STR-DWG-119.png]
Figure 29. Making sketch of the hood shell


*Figure 29. Hood shell making sketch (STR-DWG-119).*

**What it is and what it is made from.** The insulated open-bottomed pan that is pressed onto the soil. Aluminium sheet 1 mm, two skins, with 40 mm mineral wool slab between them.

**How to make it.**

1. Fold the outer pan from 1 mm aluminium, 1200 x 1000 x 250, open at the bottom, corners folded and riveted.
2. Fold the inner pan, 1120 x 920 x 210, the same way.
3. Glue hardwood blocks to the inside of the outer pan where the four handle foot plates and the inlet will go, with a 3 mm aluminium backing plate, 100 square, on the inside of each handle block. The handles carry ballast weights (section 3.29), so their bolts must clamp on wood and plate, not on wool.
4. Lay 40 mm mineral wool slab in the outer pan, set the inner pan in, and close the bottom edge all round with a riveted aluminium U-channel.
5. Cut the inlet hole, 30.6 through both skins and the block, centred across, 150 in from the end nearest the trailer.

**How it fits the parts next to it.** The skirt, manifold and handles fit on it (Figure 32).

**Check before moving on.** The hood lies flat on a floor; no wool shows.

### 3.21 Hood skirts (make 2)

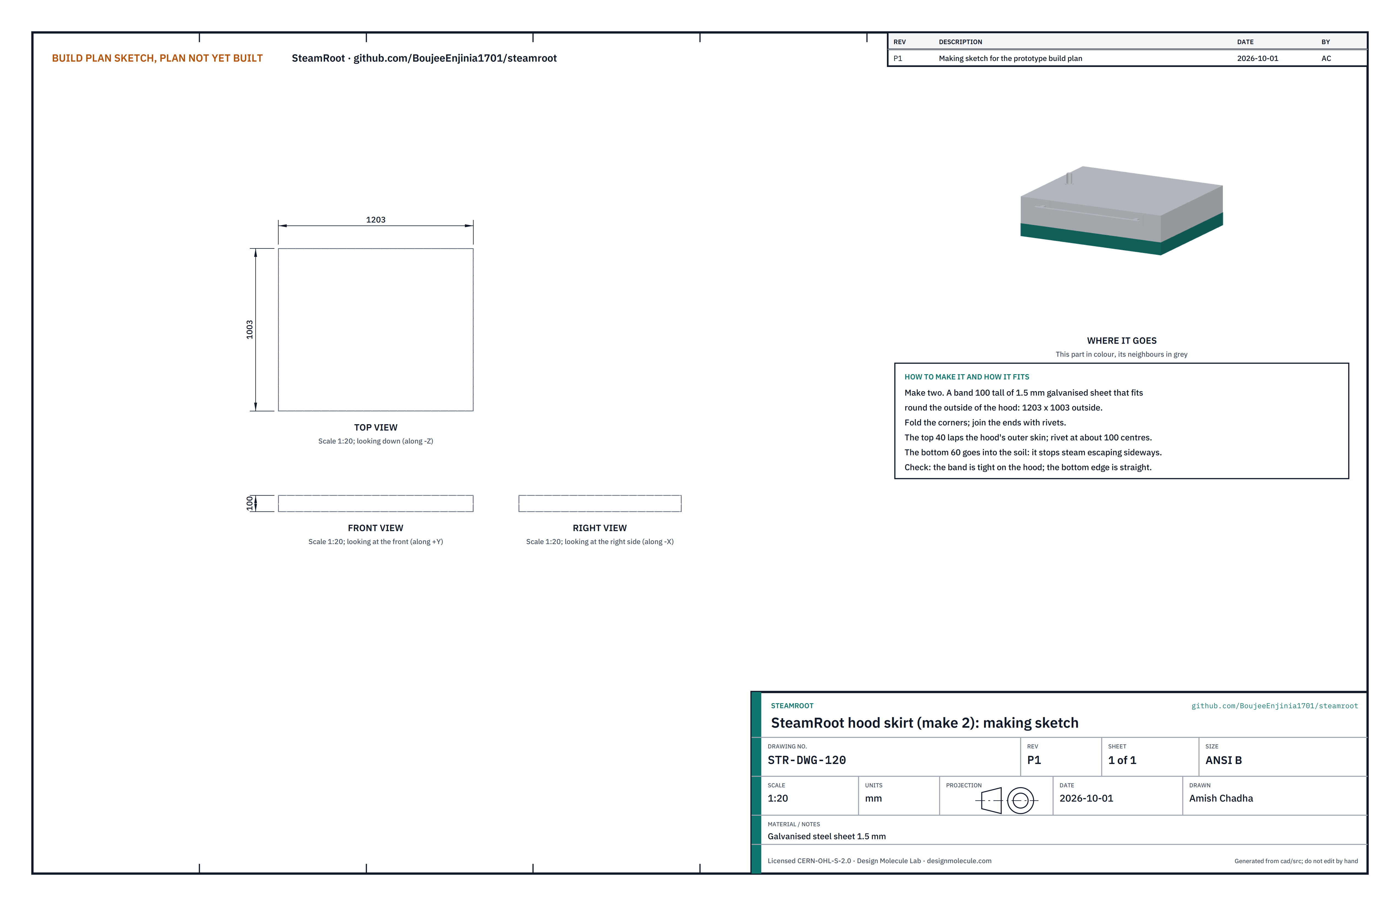
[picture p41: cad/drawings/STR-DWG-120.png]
Figure 30. Making sketch of the hood skirt


*Figure 30. Hood skirt making sketch (STR-DWG-120).*

**What it is and what it is made from.** A band round the bottom of the hood that goes 60 into the soil, so steam goes down, not sideways. Galvanised steel sheet 1.5 mm.

**How to make it.**

1. Cut a strip 100 wide and about 4420 long; fold the four corners so it fits round the hood, 1203 x 1003 outside.
2. Rivet the ends together.
3. Push it onto the hood so it laps the outer skin by 40, and rivet at about 100 centres. Do not weld galvanised steel.

**How it fits the parts next to it.** See Figure 32.

**Check before moving on.** The band is tight on the hood and its bottom edge is straight.

### 3.22 Hood manifolds (make 2)

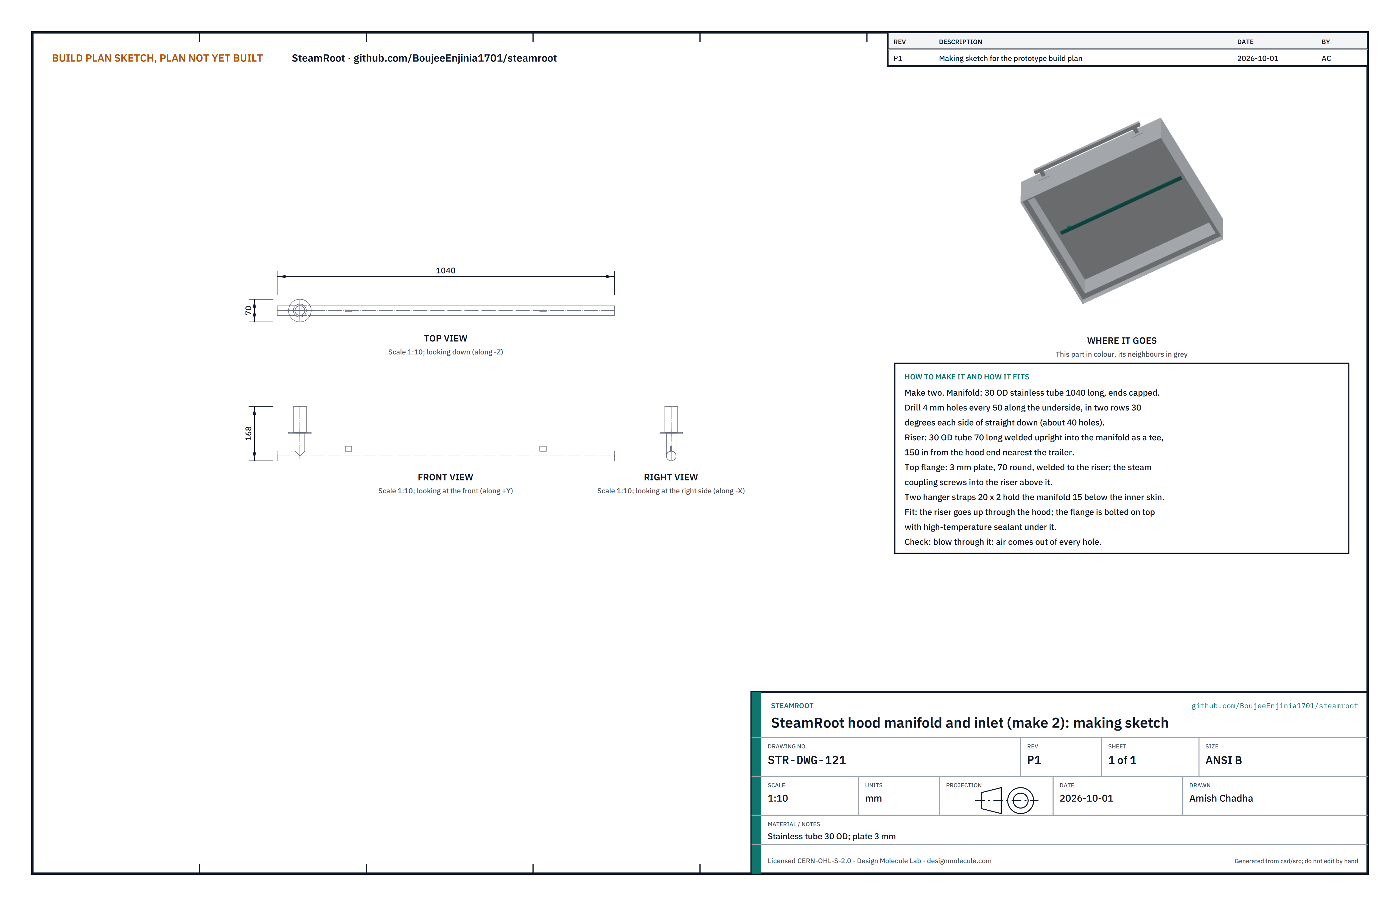
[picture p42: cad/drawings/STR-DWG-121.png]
Figure 31. Making sketch of the hood manifold


*Figure 31. Hood manifold and inlet making sketch (STR-DWG-121).*

**What it is and what it is made from.** The perforated pipe inside the hood that spreads the steam, with the riser and coupling the hose connects to. Stainless tube 30 outside diameter, 3 mm plate, a steam coupling.

**How to make it.**

1. Cut the manifold 1040 long and cap both ends.
2. Drill 4 mm holes every 50 along the underside, in two rows 30 degrees either side of straight down.
3. Weld a 70 long riser upright into the manifold as a tee, 150 from the end nearest the trailer, and a 70 round, 3 mm flange on the riser 70 above the manifold's centre line.
4. Screw the steam coupling into the top of the riser.

**How it fits the parts next to it.**

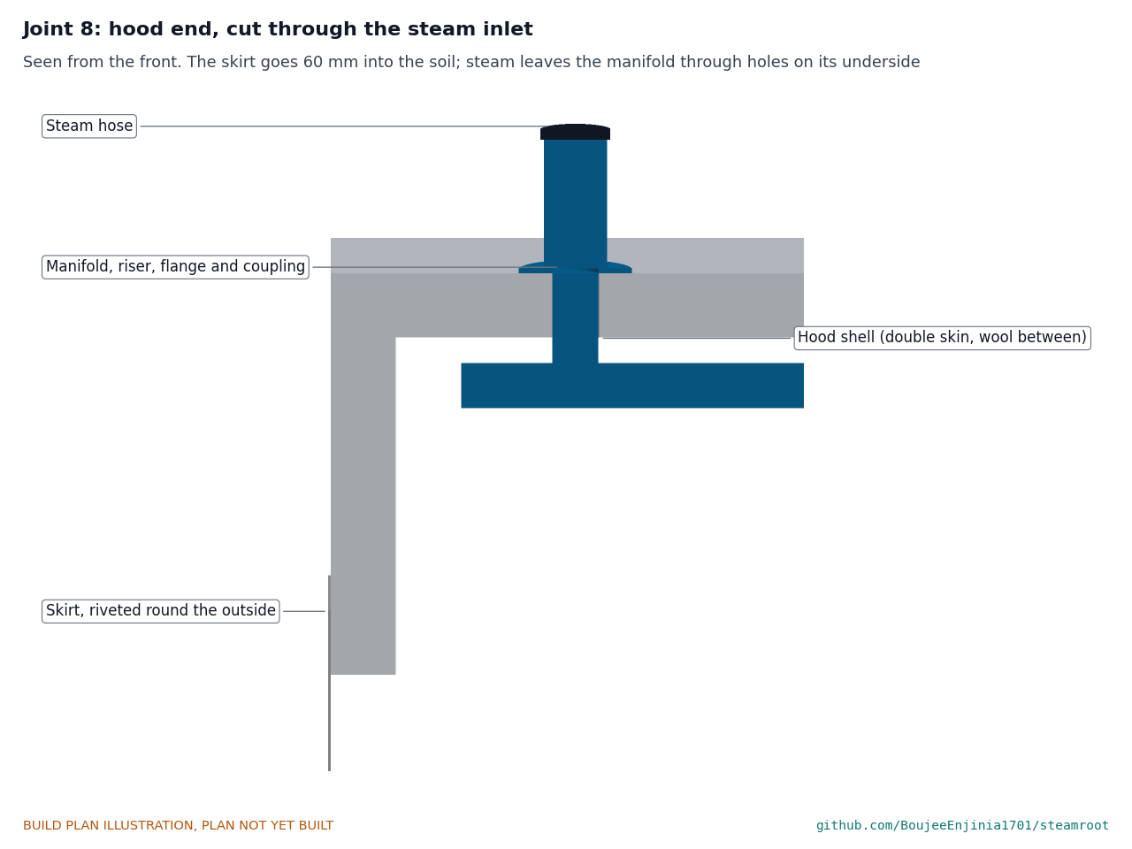
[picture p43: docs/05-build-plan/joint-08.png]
Figure 32. Joint 8: hood end, cut through the steam inlet


*Figure 32. The riser passes up through the hood; the flange is bolted down on high-temperature sealant; two straps hang the manifold 15 below the inner skin. The skirt laps the outside of the hood.*

**Check before moving on.** Blow through the coupling: air comes out of every hole.

### 3.23 Pump and alarm box and its wiring

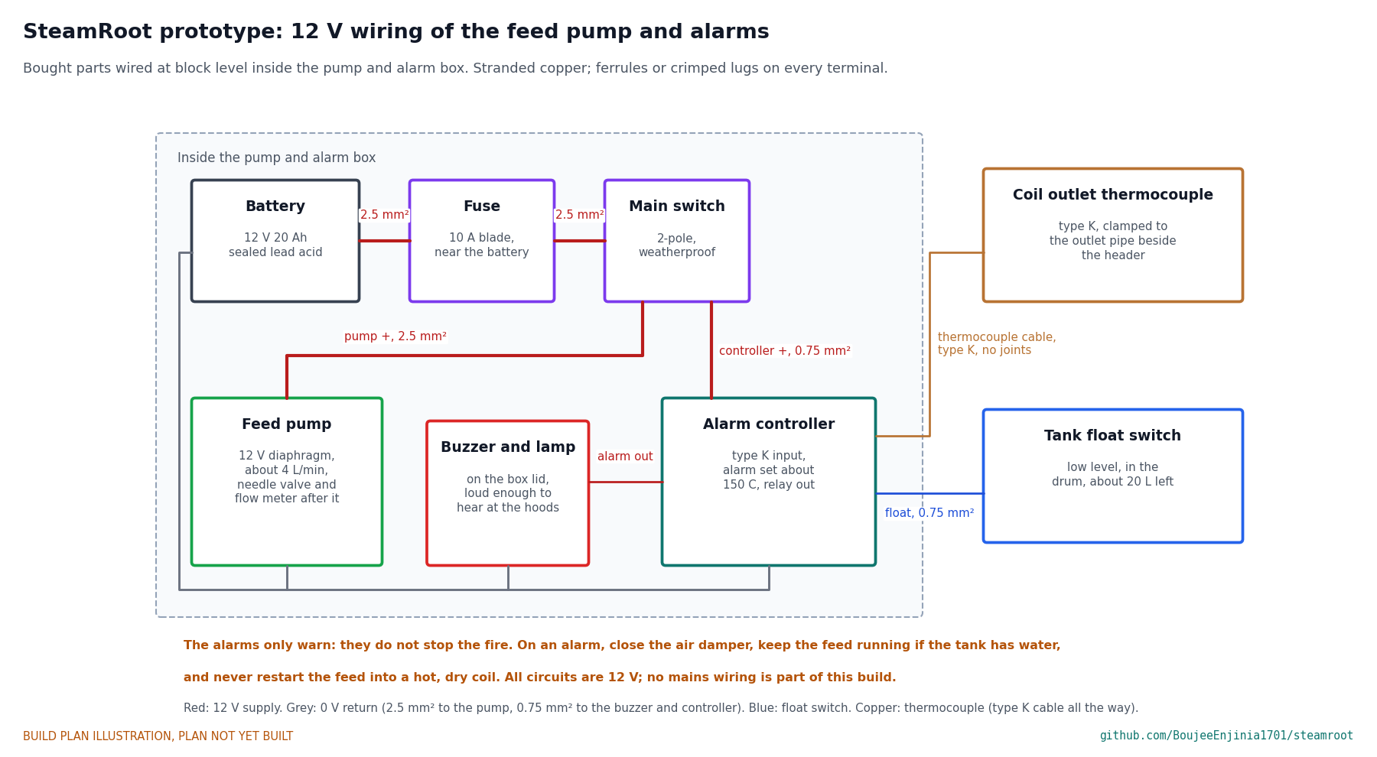
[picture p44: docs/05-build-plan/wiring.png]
Figure 33. 12 V wiring of the pump and alarms


*Figure 33. Block-level wiring of the 12 V parts. All circuits are 12 V from a sealed lead acid battery; there is no mains wiring.*

**What it is.** A weatherproof box, about 240 x 250 x 240, bolted to the deck on the left of the firebox, holding the feed pump with its needle valve and flow meter, the 12 V battery, a fuse, the main switch and the alarm controller, with the buzzer and lamp on its lid.

**What to do to it.** Mount the parts on a board in the box and wire them as Figure 33 shows: battery through a 10 A fuse and the main switch to the pump and the controller in 2.5 mm² and 0.75 mm² wire; the type K thermocouple, clamped to the coil outlet pipe beside the header, back to the controller in type K cable with no joints; the drum's float switch to the controller; the controller's relay to the buzzer and lamp. Fit a cable gland for each cable that enters the box.

**Check before moving on.** With the main switch on, heating the thermocouple with a hot air gun sounds the alarm at about 150 °C, and lifting the float switch out of water sounds it too.

### 3.24 Bought components

Buy to specification, not brand. Line numbers are those of the bill of materials.

- **Trailer (line 1).** As section 3.1.
- **Feed drum (line 3).** 125 L HDPE drum with a bulkhead outlet and strainer near the bottom of one end, a filler cap and a level sight tube.
- **Feed pump (line 4).** 12 V diaphragm pump, about 4 L/min, shut-off pressure 3 bar or less, with a needle valve and a rotameter flow meter.
- **Lining, grate, door hardware (line 5).** Ceramic fibre blanket and board rated for 1260 °C with rigidizer; 300 x 300 cast grate; two weld-on lift-off hinges; a turn latch; 12 mm ceramic rope.
- **Chimney and spark arrestor (line 8).** 150 mm single-wall stainless flue about 0.5 m and a spark arrestor cap with mesh of 6 mm or finer.
- **Header and seal fittings (line 9).** DN50 stainless pipe and caps, sockets, 114.3 and 42.2 pipe, sight tube, drain valve; 3/4 in galvanised pipe, six elbows, a half coupling and a plug for the overflow; a three-way diverter valve rated for saturated steam that cannot stop with both outlets shut; a steam-rated quick coupling.
- **Relief valve (line 10).** Certified, code-stamped steam safety valve, 15 psi (1.03 bar) set, 3/4 in, rated 170 kg/h (375 lb/h) or more.
- **Steam hose (line 11).** EPDM saturated-steam hose, 25 bore, 6 m, ground-joint couplings and whip checks.
- **Battery (line 13), instruments (line 14), alarms (line 16).** As Figure 33; a 0 to 1 bar steam gauge with a siphon; four type K thermocouples and a reader.
- **Safety kit (line 15).** Personal carbon monoxide alarm, 2A:10B:C fire extinguisher, heat-resistant gloves, face shield.
- **Pipework and fittings (lines 19 and 20).** 3.9 m of 12.7 x 1.2 stainless tube for the feed line, the economizer to bank link and the coil inlet jumper; 1 m of 16 mm suction hose; stainless compression unions, a 25.4 to 12.7 reducer, two 15.88 to 12.7 reducing unions and two bulkhead unions; 3/4 in pipe and elbow for the relief discharge; 1 in pipe, two elbows and a tee for the diverter vent line.
- **Evaporator bank tube and lining (line 22).** About 7 m of 316 stainless tube, 15.88 x 1.24 (5/8 x 0.049 in); 25 mm ceramic fibre blanket and board for the bank box.
- **Fixings and straps (line 21).** 4 x M12 x 160 bolts; 12 x M10 bolts and coach bolts; 14 x M8 x 35 bolts; 2 x M8 bolts for the overflow clip; 2 x M5 screws for the bank slot cover; 16 x M6 bolts for the hood handles; 12 x M8 and 8 x M6 weld studs; 8 x M6 bolts; two M8 U-bolts for 60 mm pipe; nyloc nuts; two 25 mm ratchet straps with lashing points; 4 m of ceramic rope gasket.

### 3.25 Evaporator bank box

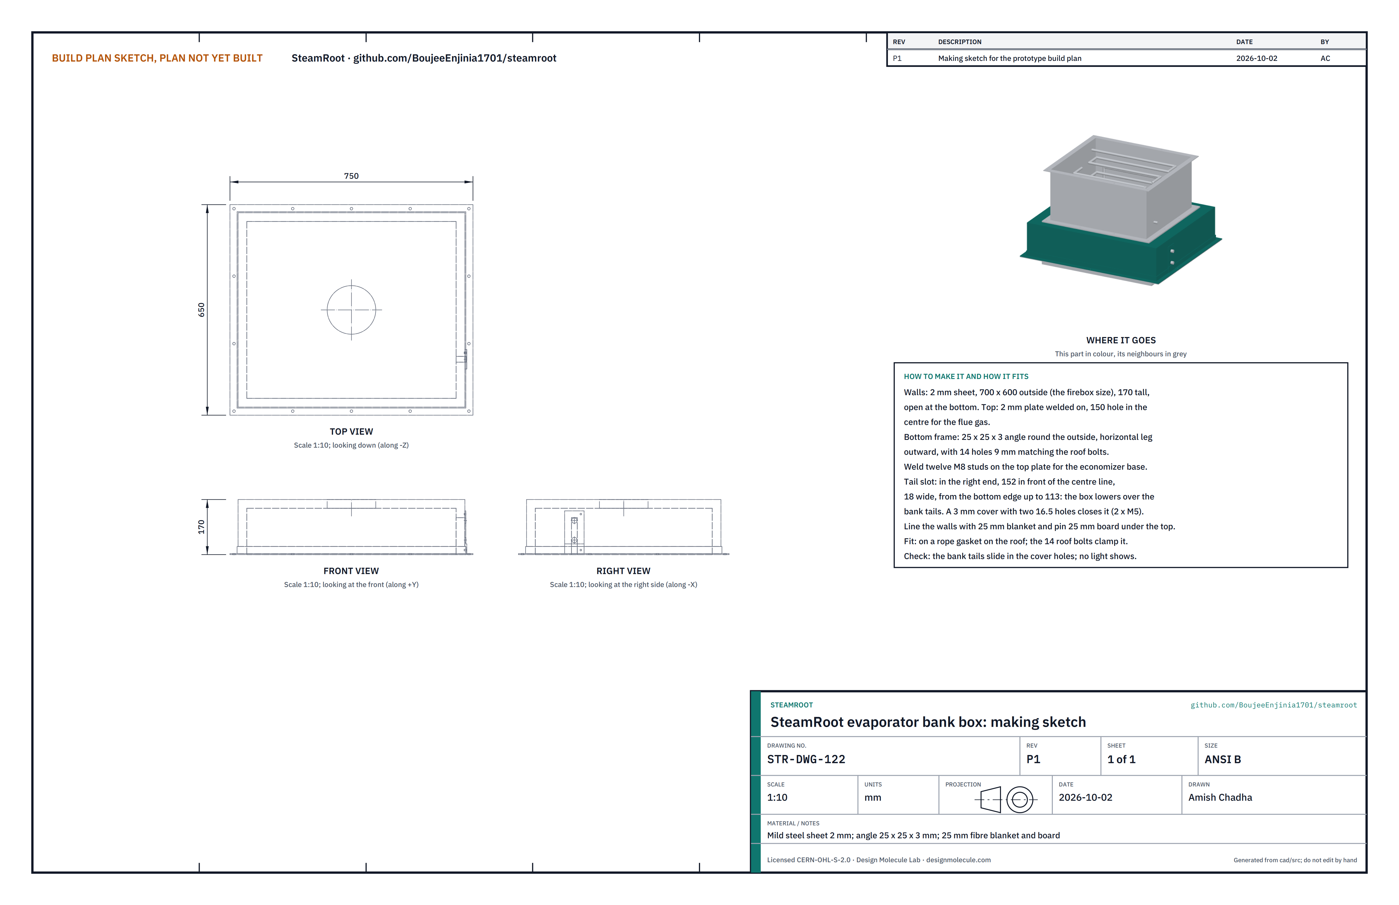
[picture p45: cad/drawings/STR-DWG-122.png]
Figure 34. Making sketch of the evaporator bank box


*Figure 34. Evaporator bank box making sketch (STR-DWG-122).*

**What it is and what it is made from.** A lined steel box that stands on the firebox roof and holds the evaporator bank in the hot gas leaving the firebox, before the gas reaches the economizer. It raises the fuel to steam efficiency from about 51 % to about 69 % with the dampers set (STR-CAL-001, section 4). Mild steel sheet 2 mm, 25 x 25 x 3 mm angle, 25 mm ceramic fibre blanket and board.

**How to make it.**

1. Fold or weld four walls of 2 mm sheet into an open box 700 x 600 outside (the size of the firebox) and 170 tall. Weld a 2 mm top plate on it with a 150 hole in the centre for the flue gas.
2. Weld a frame of 25 x 25 x 3 angle round the outside of the bottom edge, horizontal leg outward, and drill 14 holes of 9 mm in it to match the roof bolt holes (clamp it to the roof and drill through).
3. Weld twelve M8 studs on the top plate for the economizer base (mark them through the economizer base plate, section 3.12).
4. In the right end, cut a slot 18 wide from the bottom edge up to 113, centred 152 in front of the centre line, for the bank's two tails. Make a 3 mm cover plate with two 16.5 holes, 60 apart vertically, to close it, held by two M5 screws.
5. Line the walls with 25 mm blanket on stainless pins and pin 25 mm board under the top plate, cutting both round the slot and the flue hole.

**How it fits the parts next to it.** The bank sits on its bars on the roof first; the box is lowered over it, the tails passing up the slot, and the 14 roof bolts clamp its frame to the roof (Figure 35). The economizer stands on its top plate.

**Check before moving on.** The tails slide freely in the cover holes; with a lamp inside, no light shows at the frame or the slot.

### 3.26 Evaporator bank tube and supports

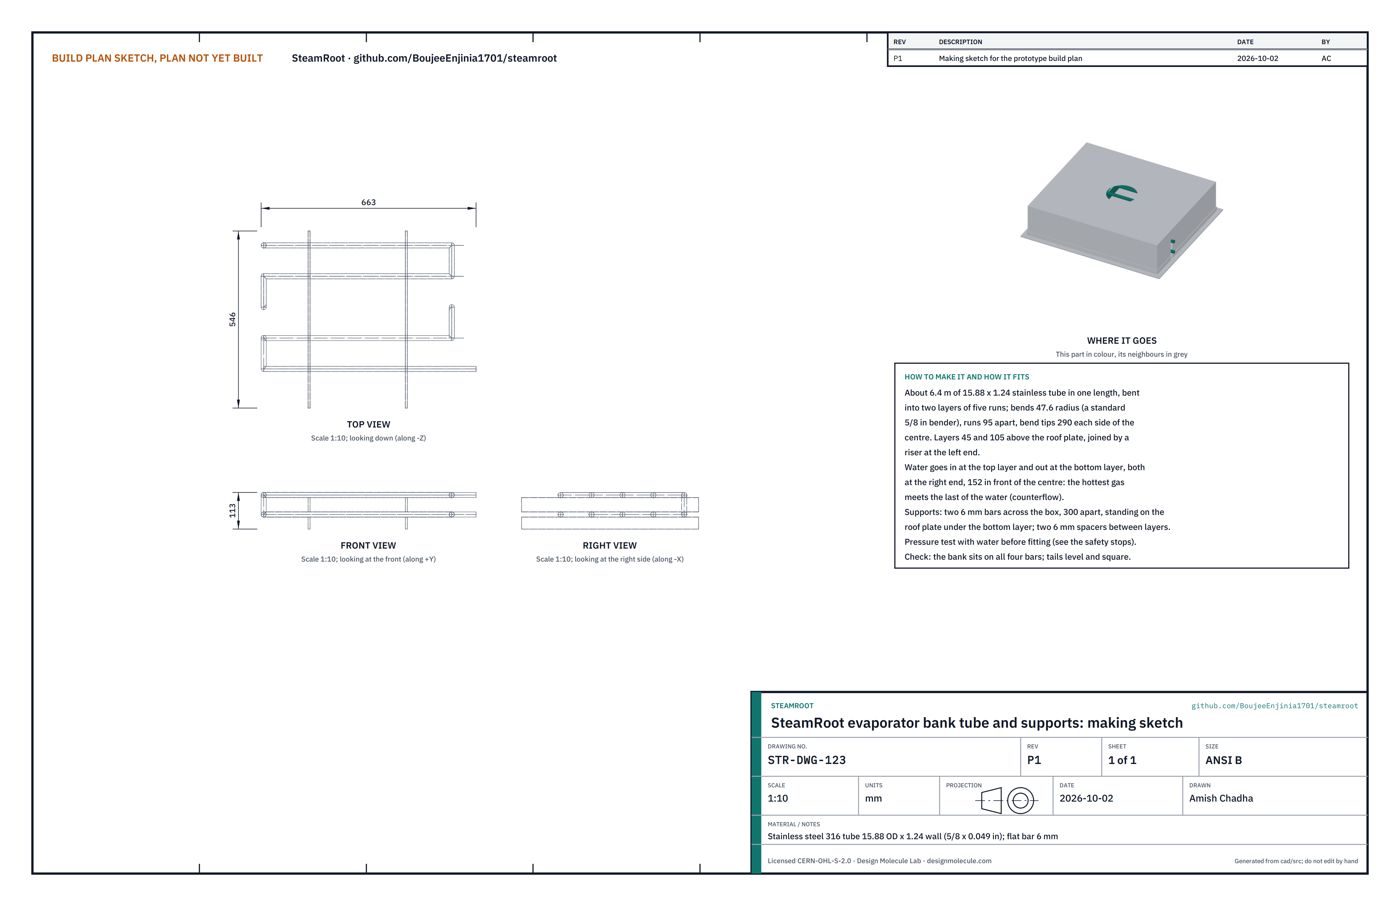
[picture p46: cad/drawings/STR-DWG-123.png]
Figure 35. Making sketch of the evaporator bank tube


*Figure 35. Evaporator bank tube and supports making sketch (STR-DWG-123).*

**What it is and what it is made from.** A serpentine of stainless tube in which the feed water, warmed by the economizer, starts to boil before it goes down to the coil. About 6.4 m of stainless steel 316 tube, 15.88 outside diameter, 1.24 wall (5/8 x 0.049 in), and 6 mm flat bar.

**How to make it.**

1. Bend the tube in one length into two layers of five straight runs, with the bends at 47.6 radius (a standard 5/8 in hand bender), the runs 95 apart and the bend tips 290 each side of the centre. Join the layers with a riser at the left end.
2. Leave both ends straight at the right end, 152 in front of the centre line, one in the top layer (the inlet) and one in the bottom layer (the outlet), long enough to end 15 outside the box.
3. Cut two support bars from 6 mm flat bar, 546 long and 37 tall, and two spacers 546 long and 44 tall.
4. Pressure test the bank cold to 3 bar with water; hold 10 minutes with no fall and no leak.

**How it fits the parts next to it.** The two bars stand on the roof plate 300 apart across the box, the bottom layer rests on them, the spacers sit between the layers, and the top layer rests on the spacers. Water enters the top layer from the economizer and leaves the bottom layer for the coil, so the last of the water meets the hottest gas. A 15.88 to 12.7 reducing union on each tail joins the 12.7 link and jumper (step 18). Together the bank, coil, economizer and header hold about 7.3 L of water when flooded, inside the 8 L limit.

**Check before moving on.** The bank sits on all four bars without rocking; the tails are level and square to the wall.

### 3.27 Secondary air damper

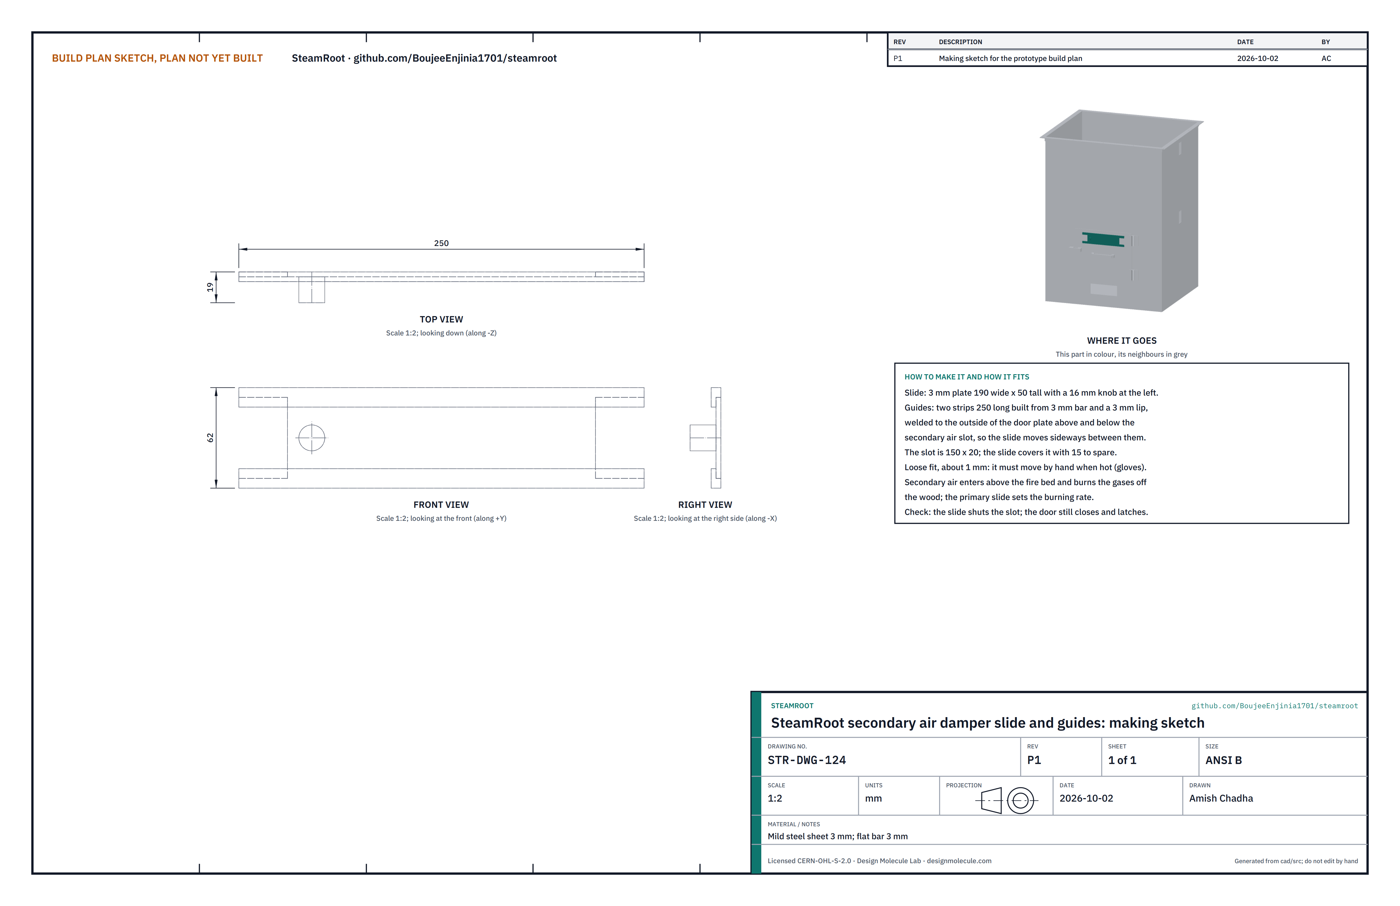
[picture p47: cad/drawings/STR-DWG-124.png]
Figure 36. Making sketch of the secondary air damper


*Figure 36. Secondary air damper slide and guides making sketch (STR-DWG-124).*

**What it is and what it is made from.** A small slide on the door over the secondary air slot. Air let in above the fire bed burns the gases that come off the wood; with the primary damper it holds the excess air near 1.5. Mild steel sheet 3 mm and 3 mm bar.

**How to make it.**

1. Cut the slide 190 wide x 50 tall from 3 mm sheet and weld a 16 mm knob near its left end.
2. Make two guides 250 long from 3 mm bar with a 3 mm lip, and weld them to the outside of the door plate above and below the slot so the slide runs between them.

**How it fits the parts next to it.** The slide is a loose fit, about 1 mm, so it moves by hand when hot (Figure 11). It clears the latch and the upper hinge by at least 10.

**Check before moving on.** The slide shuts the slot and moves freely; the door still closes on its rope and latches.

### 3.28 Seal pot overflow and loop seal

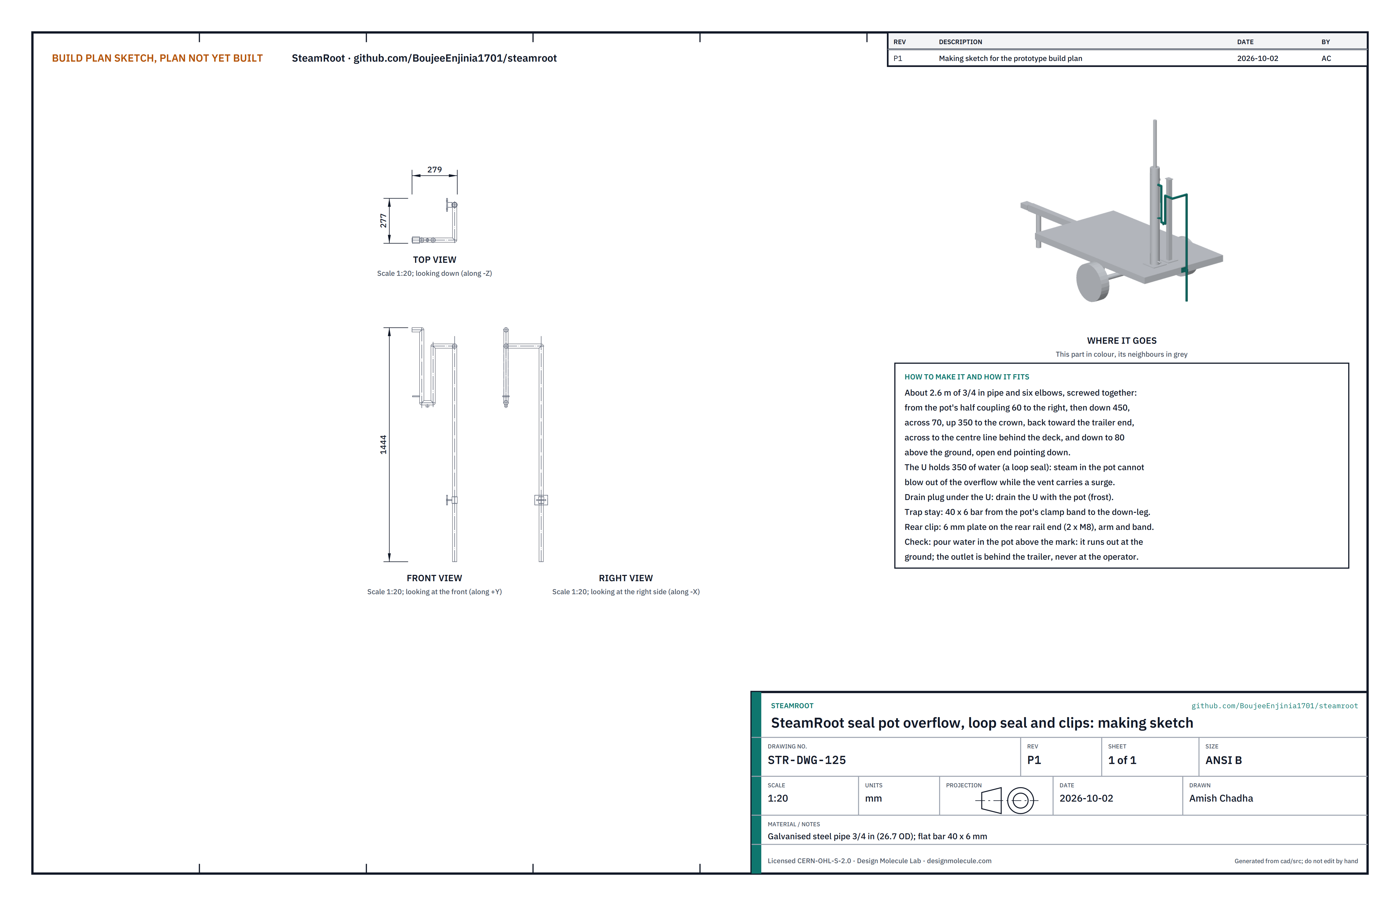
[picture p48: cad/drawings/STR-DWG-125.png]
Figure 37. Making sketch of the seal pot overflow


*Figure 37. Seal pot overflow, loop seal and clips making sketch (STR-DWG-125).*

**What it is and what it is made from.** A pipe that takes any water above the mark out of the seal pot and down to the ground behind the trailer, away from the operator's side, so the pot can never be overfilled and the seal limit can never rise. About 2.6 m of 3/4 in galvanised pipe, six elbows, a plug, 40 x 6 mm flat bar and a clamp band.

**How to make it.**

1. Screw the pipe together from the pot's half coupling: 60 to the right, down 450, across 70, up 350 to the crown, back toward the rear of the trailer, across to the centre line just behind the deck, and down to 80 above the ground with the open end pointing down.
2. The U between the down-leg and the up-leg holds 350 of water, a loop seal: it stops steam in the pot leaving by the overflow when the vent carries a surge (it holds about 3.3 kPa against about 2.4 kPa). Fit a drain plug under the U.
3. Make the trap stay from 40 x 6 bar, welded to the pot's clamp band and clamped to the down-leg, and the rear clip: a 6 mm plate bolted to the end of the rear rail with two M8 bolts, an arm and a band round the down-pipe.

**How it fits the parts next to it.** See Figure 25. The open end is behind the trailer, at least 1 m from the firebox door.

**Check before moving on.** Water poured into the pot above the mark runs out of the open end at the ground, and the U stays full.

### 3.29 Hood handles for ballast (make 2 sets)

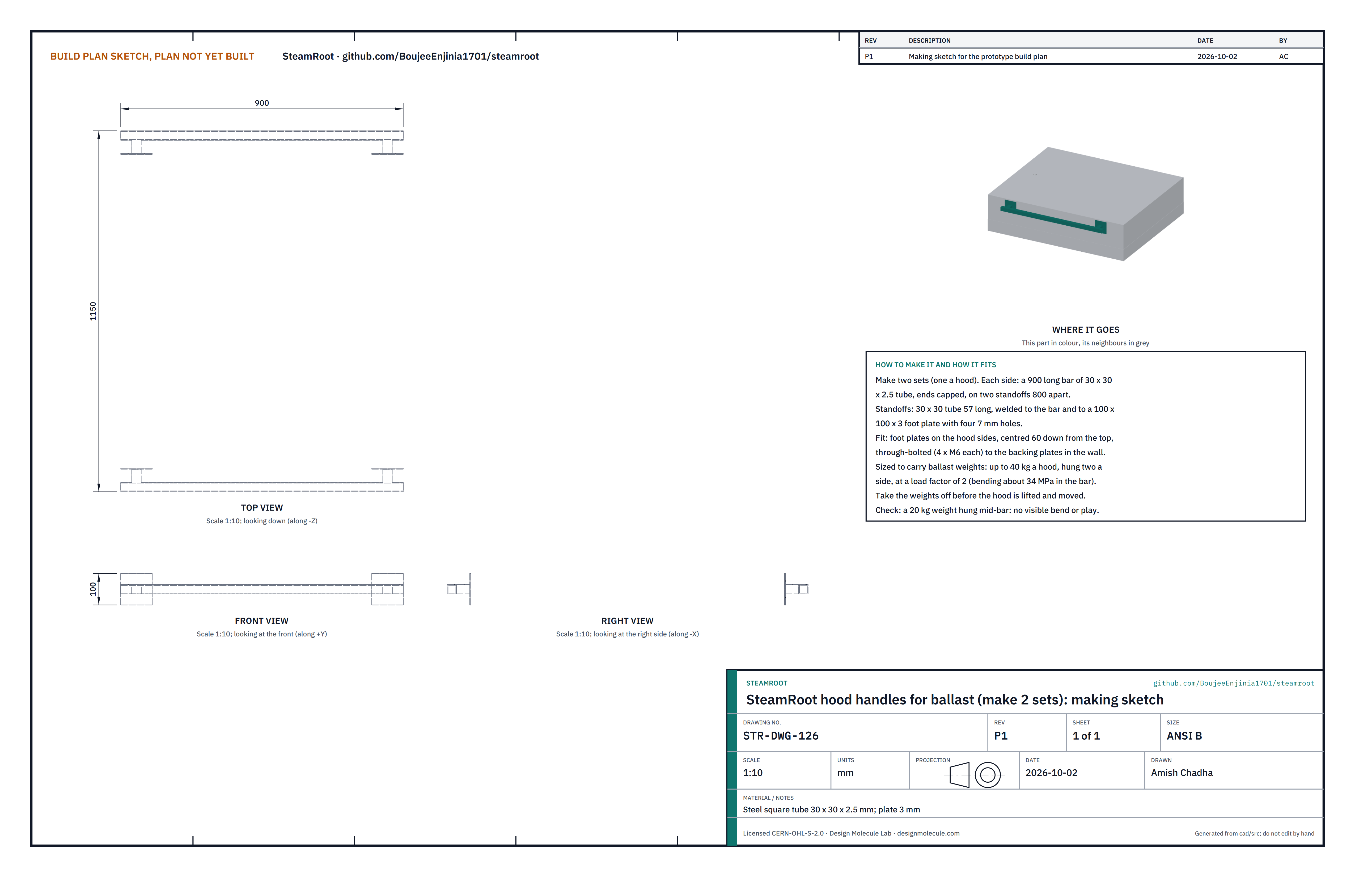
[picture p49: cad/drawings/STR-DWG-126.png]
Figure 38. Making sketch of the hood handles


*Figure 38. Hood handles making sketch (STR-DWG-126).*

**What it is and what it is made from.** Two handles on each hood, strong enough to carry ballast weights that press the hood and its skirt onto the soil. Steel square tube 30 x 30 x 2.5 and 3 mm plate.

**How to make it.**

1. For each side, cut a 900 bar of 30 x 30 x 2.5 tube and cap its ends.
2. Weld two standoffs of 30 x 30 tube, 57 long, under the bar 800 apart, and weld each to a 100 x 100 x 3 foot plate with four 7 mm holes.

**How it fits the parts next to it.** The foot plates are bolted through the hood wall, the hardwood block and the backing plate (section 3.20) with four M6 bolts each, centred 60 below the top of the hood. Each hood's handles carry up to 40 kg of ballast, two weights a side, at a load factor of 2; the bar then sees about 34 MPa, a seventh of its yield strength. With 40 kg on, the hood presses on the soil with about 580 Pa and the header pressure rises only to about 0.036 bar. How much ballast is needed is found in the soil tests at TRL 4. Take the weights off before a hood is lifted.

**Check before moving on.** A 20 kg weight hung at the middle of a bar causes no visible bend or play.

## 4. Putting it together

In each picture the parts already fitted are grey and the part being fitted is in colour, with an arrow showing the way it goes in.

### Step 1: skids under the firebox shell

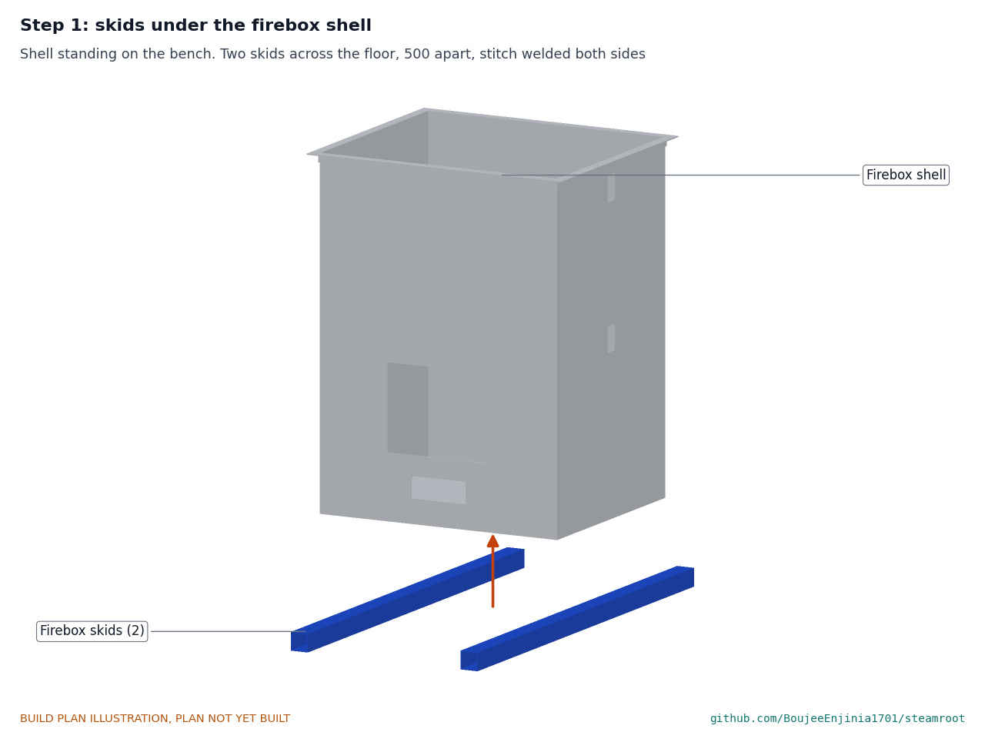
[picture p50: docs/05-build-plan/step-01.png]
Step 1


With the shell upside down on the bench, lay the two skids across the floor, 500 apart and 100 in from each end, and stitch weld them both sides (section 3.3).

### Step 2: weld on the brackets, guides and hinge leaves

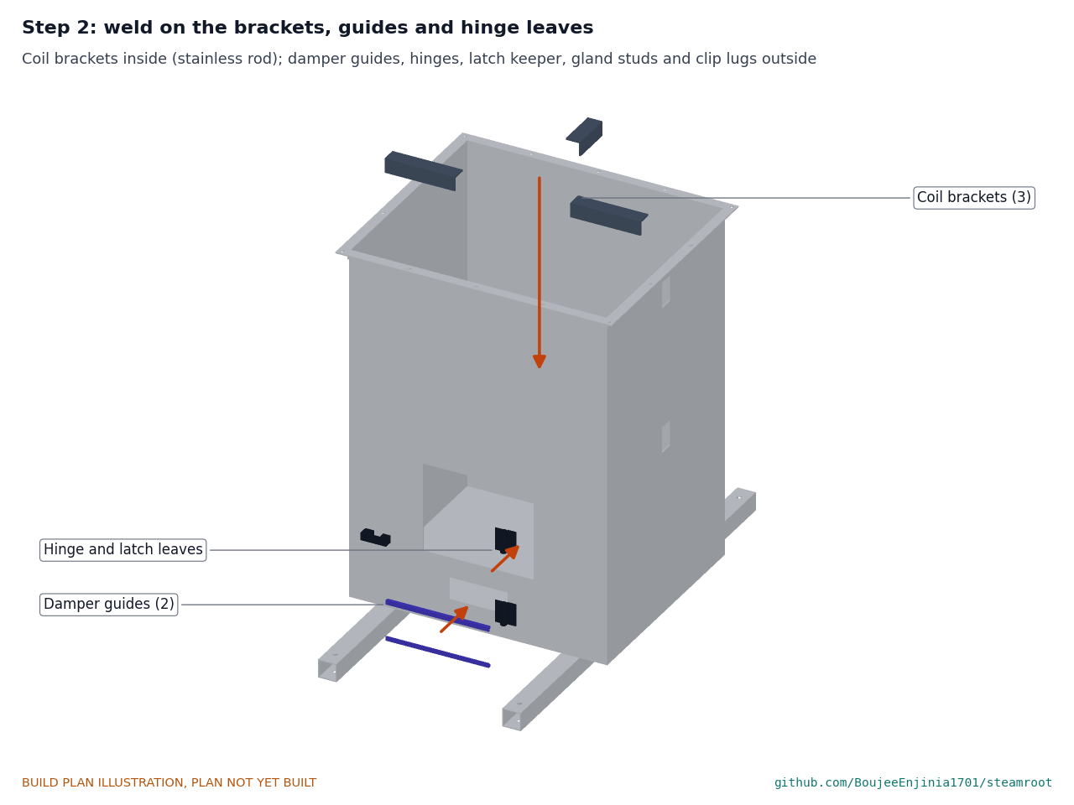
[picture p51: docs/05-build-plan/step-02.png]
Step 2


Weld the three coil brackets inside (section 3.4) and the damper guides, hinge leaves, latch keeper, gland studs and clip lugs outside (sections 3.2, 3.7, 3.8). **Hold point:** all welding on the shell is finished before the lining goes in.

### Step 3: firebox onto the trailer

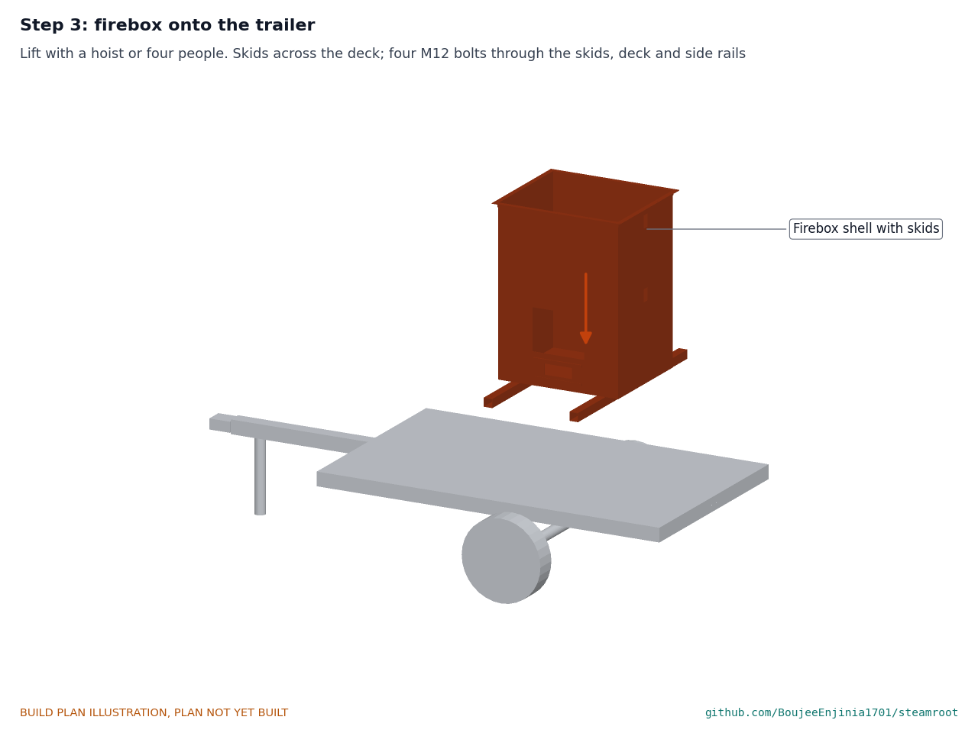
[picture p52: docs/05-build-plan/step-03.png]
Step 3


Lift the shell onto the deck with a hoist or four people, skids across the deck, the firebox centred on the deck's centre line with its right face 400 from the right end of the deck. Drill through the skid holes into the deck and side rails and fit four M12 bolts, nyloc nuts under the rails.

### Step 4: fibre lining into the firebox

Step 4

Floor board first, then the two layers of wall blanket over the pins, cut round the openings, slots and brackets (section 3.5). Wear the protective equipment in section 7.

### Step 5: grate stand and grate

Step 5

Lower the stand in through the open top onto the middle of the floor board and set the grate on it.

### Step 6: door and air dampers

Step 6

Lift the door onto its hinges and check it latches. Slide the primary damper into its guides on the shell and the secondary damper into its guides on the door, both from the side.

### Step 7: coil into the firebox

Step 7

With a helper, lower the coil in through the open top with its tails toward the right end, held 66 toward the left and 30 above the brackets, so the tail ends clear the lining. Slide it to the right so the tails pass out through the slots, then set it down onto the three brackets. **Hold point:** the coil rests on all three brackets and both tails sit in the bottom of their slots; shim a bracket if needed.

### Step 8: gland plates over the coil tails

Step 8

Pack each slot round its tail with ceramic rope, slide a gland plate over each tail end and nip the four M6 nuts so the rope seals but the tube still slides.

### Step 9: roof onto the firebox

Step 9

Lay ceramic rope on the top frame, lower the roof and board on, and fit the 14 M8 bolts, nuts under the frame, tightened evenly.

### Step 10: tube bank into the economizer box (on the bench)

Step 10

Lower the tube bank onto the two support bars and connect each end to its bulkhead union.

### Step 11: evaporator bank, economizer and lid onto the roof

Step 11

Stand the two support bars on the roof, set the bottom layer of the bank on them with its tails to the right, and fit the spacers. Lay rope gasket round the roof edge, lower the bank box over the bank so the tails come up the slot, and fit the slot cover. Fit the 14 M8 x 35 bolts through the box frame, roof and top frame, tightened evenly. Lay rope gasket on the box top round the flue hole, set the economizer over the twelve studs and fit the nuts. Lay rope on the top flange and bolt the lid on with eight M6 bolts.

### Step 12: chimney and spark arrestor

Step 12

Slide the chimney over the spigot and fix it with three self-drilling screws; push the spark arrestor cap onto its top. Check the mesh is in place.

### Step 13: header post and header

Step 13

Stand the post on the deck 130 right of the firebox on the centre line, mark and drill the deck, and fit four M10 bolts. Lay the header on the saddle, sockets as section 3.16, and fit the two U-bolts.

### Step 14: coil outlet pipe to the header

Step 14

Bend the outlet pipe from 25.4 stainless tube to fit from the union on the upper tail to the header's side socket: out 25, up 94, across 40. Fit the union on the tail and screw the other end into the header. Tighten the union last, so nothing strains the coil.

### Step 15: water-seal pot, stay and overflow

Step 15

Stand the pot on the deck in front of the post, its branch lined up with the header's front cap. Mark, drill and bolt its foot plate (four M10). Join the branch; bolt the stay's band round the pot and weld the stay to the post. Screw the overflow into the half coupling at the water mark, clamp the trap stay to the down-leg, and bolt the rear clip to the end of the rear rail round the down-pipe.

### Step 16: relief valve and diverter

Step 16

Screw the relief valve upright into its socket on top of the header, lever toward the front, and fit the discharge pipe from its outlet up to 2.3 m with the stay to the vent pipe. Screw the diverter onto the header's back nipple with its hose coupling pointing right, and fit the vent line from its vent port up and into the vent pipe's tee. **Hold point:** safety stop S4.

### Step 17: feed drum on its saddles

Step 17

Bolt the saddles across the deck, 440 apart, with M10 coach bolts. Lay the drum in them with its outlet toward the back, and fit the two ratchet straps to the lashing points.

### Step 18: pump box and feed lines

Step 18

Bolt the pump and alarm box to the deck at the back edge, just right of the drum. Run the suction hose from the drum outlet to the pump. Bend the stainless feed line from the pump up the left end of the firebox, through its two clips, to the economizer inlet union. Bend the link from the economizer outlet union out and down to the bank's top tail, with a reducing union on the tail. Fit the reducer and union on the lower coil tail and bend the jumper up the right end to the reducing union on the bank's bottom tail. **Hold point:** safety stop S3.

### Step 19: build each hood (on the bench, make two)

Step 19

With the hood upside down, hang the manifold from the inner skin on its two straps with the riser up through the inlet hole; bolt the flange down on sealant on top. Rivet the skirt round the outside. Bolt the handles' foot plates through the hood wall, the hardwood blocks and the backing plates.

### Step 20: steam hose to a hood

Step 20

Couple the hose to the diverter and to the hood in use, and fit the whip checks at both ends. **Hold point:** safety stops S5 and S6.

## 5. First checks

These are the checks a TRL 4 test report would record; this plan only lists them. Requirement numbers are those of STR-REQ-001.

*Table 2. First checks.*

| Check | Requirement | How | Pass when |
| --- | --- | --- | --- |
| Open path to the vent | R6 | Cold, empty: with the diverter in each of its positions, blow low-pressure air into the bank inlet | Air always leaves by the vent or the hose; no position closes both |
| Seal limit | R6 | Pot filled to the mark with cold water; raise the header pressure slowly with air through a regulator; watch the gauge | Steam path opens (air bubbles through) at 0.08 to 0.09 bar; water above the mark leaves by the overflow; no water leaves the vent |
| Water in the heated section | R7 | Fill the coil, bank, economizer and header; drain and measure | 8 L or less (7.3 L calculated) |
| Leak test, steam side | R6, R7 | Cold water at 3 bar for 10 minutes, seal pot branch plugged for the test only | No leak, no pressure fall; plug removed |
| Feed rate | R3, R8 | Set the needle valve; time a measured volume at the coil inlet | 0.5 L/min (30 kg/h) |
| Alarms | Feed control (STR-DDR-001) | Heat the thermocouple with a hot air gun; lift the float switch | Alarm sounds at about 150 °C and at about 20 L left |
| Relief valve | R9 | Read the nameplate and code stamp; lift the test lever cold | 15 psi set; 170 kg/h or more; lever moves freely |
| Chimney and mesh | R10 | Measure the outlet height and the mesh | 2.2 m or more (2.4 m); mesh 6 mm or finer |
| Mass and width | R11 | Weigh on a weighbridge with the drum and pot drained; measure the width | 500 kg or less (499 kg estimated with both hoods aboard, 437 kg without); 1.5 m or less (1.48 m) |
| Steam output and pressure (first fire) | R3, R6 | With feed at 0.5 L/min, fire to steady steam at the hood; read the header gauge | Dry steam at the hood; header 0.1 bar or less |
| Hood handles | R10 | Contact thermometer on the handles and outer skin after 30 minutes of steaming | 60 °C or less |
| Run per fill | R8 | Time from a full drum to the low-level alarm | 3 h or more (4.2 h calculated) |
| Soil temperature | R1 | Type K probes at 15 cm under a hood | 70 °C or more for 20 to 30 minutes over 80 % of the footprint |

## 6. Safety stops

Stop at each point. Carry on only when everything listed is true.

- **S1. Before anything is bought or built.** A written ruling from the local boiler authority (the Texas Department of Licensing and Regulation's boiler program) on this open-vented, wood-fired monotube coil is in hand, and the design has been checked against it. Its ruling overrides this plan where it is stricter.
- **S2. Before welding, grinding or cutting fibre.** Hot work area clear of anything that burns, extinguisher at hand, welding screen up. Cut ceramic fibre with a knife, damp, never with a power saw; wear a P2 (FFP2) mask, gloves and long sleeves, and vacuum, never sweep. Never weld galvanised steel.
- **S3. Before any water goes into the coil, bank or economizer.** Every joint is made up; the coil, the evaporator bank and the economizer have passed their 3 bar cold tests; the seal pot branch is open (no test plug left in).
- **S4. Before the seal pot is put in service.** The vent is open from the pot to its outlet at 2.3 m; the diverter cannot stop with both outlets shut; nothing on the steam side can isolate the coil from the vent; the relief valve is fitted upright with its discharge pipe open to 2.3 m; the pot is free of ice and filled to the mark; the overflow is clear to its open end behind the trailer, its loop seal is full of water, and no one stands near its outlet.
- **S5. Before the first fire.** All first checks up to "Run per fill" in section 5 pass, except the ones that need fire. The machine stands on bare ground or gravel, clear of dry vegetation, outdoors, with no fire ban and no high wind. Extinguisher and water at hand; the operator wears a personal carbon monoxide alarm, heat-resistant gloves, a face shield, long sleeves and closed boots; bystanders, children and animals at least 5 m away. The feed pump is running and water flows before the fire is lit: never fire a dry coil.
- **S6. Before steam goes to a hood.** The diverter is set to the vent; the hose and whip checks are inspected; the hood is set on the soil with its skirt pressed in. Keep hands and feet clear of the skirt and the vent outlet.
- **S7. Before lifting a hood or moving the hose.** Steam has been diverted to the vent for at least one minute.
- **S8. After any alarm.** Close both air dampers. Never restart the feed into a hot, dry coil: let the fire die and the coil cool first.
- **S9. Before towing.** The fire is out and cold; the drum and seal pot are drained; the hoods are off the trailer and ride on a second vehicle; the lights work.
- **S10. After every day of use and whenever frost is forecast.** The seal pot is drained through its valve and the overflow's loop seal through its plug.

## 7. Tools, skills and workspace

**Tools.** MIG welder for 2 to 3 mm mild steel; stick or TIG welder with 309 rod for the stainless brackets and 316 rod for the stainless header; angle grinder with cutting, grinding and flap discs; plasma cutter or jigsaw with metal blades for sheet; bench drill and drills to 13 mm; step drill; 150 mm hole saw or plasma for the flue holes; sheet metal folder (or clamped angle and mallet) for the 1 mm hoods and the 1.5 mm skirts; pop rivet tool; hand tube benders for 1/2 in tube, 38 mm radius, and 5/8 in tube, 47.6 mm radius; a 395 mm coil former and spacer blocks; pipe wrenches, spanners and a torque wrench; thread sealant rated for steam; utility knife for the fibre; tape measure, square, level and spirit level; hydraulic hand pump and gauge to 4 bar for the cold tests; multimeter; hot air gun; a hoist or four people for lifting the firebox.

**Skills.** Welding mild steel sheet and tube to a sound, leak-free standard, and stainless to mild steel; bending tube without kinks; threaded and compression pipe fitting; folding and riveting sheet; 12 V wiring. Steam pipework must be fitted by someone who has done it before or is supervised by someone who has. No mains wiring is part of this build.

**Workspace.** A fabrication workshop with a concrete floor and room for the trailer and a 2 x 1 m bench; a separate bench for the hoods; good ventilation for welding; a wet area for the cold pressure tests. First fire outdoors only, on bare ground or gravel.

**Personal protective equipment.** Welding helmet, gloves and jacket; safety glasses and hearing protection for grinding and cutting; P2 (FFP2) mask, gloves and long sleeves for ceramic fibre and mineral wool; heat-resistant gloves, face shield, long sleeves and closed boots for any work near a fire or steam; a personal carbon monoxide alarm at any fire.

## 8. Where the numbers come from

- Model and constructability checks: `cad/src/model.py` (`python cad/src/model.py --check`, 124 checks); STEP and STL exports in `cad/step/` and `cad/stl/`.
- Pictures: `cad/src/build_plan_media.py`, using `.kit/build_views.py`; written to `docs/05-build-plan/` and `cad/drawings/STR-DWG-101` to `STR-DWG-126`.
- General arrangement: `cad/drawings/STR-DWG-002.pdf`, Rev P4.
- Calculations: `docs/04-calcs/01-sizing.md` (STR-CAL-001 v0.4) and `docs/04-calcs/sizing.py`; evaporator bank and dampers section 4, masses section 7, pressures and seal section 5, stored water and the overflow section 6.
- Bill of materials: `bom/bom.csv`.
- Decisions: `docs/decisions/0003-design-for-construction.md` (STR-DDR-003), with STR-DDR-001 and STR-DDR-002; open decisions in `docs/06-design-decisions.md` (STR-DEC-001).
- Requirements: `docs/03-requirements.md` (STR-REQ-001 v0.7).

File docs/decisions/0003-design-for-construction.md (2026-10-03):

---
doc_id: STR-DDR-003
title: SteamRoot design for construction
project: SteamRoot
doc_type: Design decision record
version: "0.3"
status: Draft
date: '2026-10-02'
author: Amish Chadha
license: CERN-OHL-S-2.0
revisions:
- version: "0.1"
  date: '2026-10-01'
  author: Amish Chadha
  change: Changes that make the concept physically buildable, with the reason for each; made under Amish's 2026-09-30 instruction to make the design physically buildable; open for his review
- version: "0.2"
  date: '2026-10-02'
  author: Amish Chadha
  change: "Accepted by Amish on 2026-10-02 (Tables 1 to 3); seal pot overflow accepted but not yet modelled; record stays Draft"
- version: "0.3"
  date: '2026-10-02'
  author: Amish Chadha
  change: "A1 and A2 carried into the model: firebox reshaped to 960 mm inside the evaporator bank study; seal pot overflow with a 350 mm loop seal modelled and checked (STR-CAL-001 v0.4)"
---

# 0003: Design for construction

- **Date:** 2026-10-01
- **Status:** accepted. The changes in Tables 1 and 2 were made under Amish's 2026-09-30 instruction to make the design physically buildable. Amish, 2026-10-02: "i approve your recommendations for all 555 open decisions." This covers every change in Tables 1 and 2 and the recommendations in Table 3 (A1 to A3), recorded in the design decisions register (STR-DEC-001, items 5 to 7 and 10). The seal pot overflow (A2) was added to the model on 2026-10-02 with a 350 mm loop seal; with the overflow the seal limit is 0.084 bar (STR-CAL-001 v0.4). For A1, the evaporator bank study reshaped the firebox to 960 mm with one coil turn fewer. The record stays Draft.

> **Safety:** Changes C6, C8 and C9 touch the open vent, the water seal and the relief valve. Each keeps the safety case of STR-PRC-001 as it stands (an open vent that cannot be isolated, a 0.094 bar seal limit, a certified 15 psi relief valve rated 170 kg/h); none changes it. The written ruling from the local boiler authority (the Texas Department of Licensing and Regulation's boiler program, decided 2026-10-02) is still an open prerequisite for any build, and its ruling overrides this record if it is stricter.

## Context

On 2026-09-30 Amish asked for a build plan that shows how each component is made and how it fits the next, with pictures, and wrote: "If you are realising that the design cannot be built as per concept - fix the design assumptions to match and be physically feasible as you draw the illustrations." The TRL 3 model (STR-DDR-002) was a massing model: it showed what SteamRoot does, but checking it with build123d found parts that overlap, float, have no fixing or cannot be put together in any order. A pairwise overlap check of the concept model found six clashes (the seal pot through the deck, the coil through the firebox lining and walls, the coil outlet into the header, the hose through the deck edge and into the hood, the relief valve into the header), and a review of each joint found the rest.

The changes keep what SteamRoot does: an open-vented, wood-fired monotube coil making 30 kg/h of steam at about 0.03 bar, an economizer, a 1 m water seal, a certified relief valve, one hose and two hoods on a towed trailer. Every change is in `cad/src/model.py`, which now runs 93 constructability checks (`python cad/src/model.py --check`): parts that must touch do touch without overlapping, parts that must not touch are apart by at least the stated clearance, and the coil can be lowered into the firebox and slid into place. All 93 pass.

## Decision

*Table 1. Changes made to the model, the BOM and the calculations.*

| # | Problem in the concept | Change made | Why this way |
| --- | --- | --- | --- |
| C1 | The coil filled the firebox from 90 mm above the floor to the roof (its top turn cut 11 mm into the roof lining), so there was nowhere to put the wood: the door covered a closed wall and opened onto the coil, and the grate (60 mm up) sat across the air damper. | Firebox 1000 mm tall (was 650), same 700 x 600 mm footprint. The coil keeps its 11 turns, 420 mm diameter and 40 mm pitch but sits above the fire: its lowest turn is 400 mm above the floor board. Below it, a 300 x 240 mm door opening, a 300 x 300 mm cast grate on a stand 100 mm up (the ash pit), and a 160 x 60 mm air inlet under the grate with a slide damper. 280 mm of fire space between the grate and the coil. | The coil cannot surround a fire that has to be fed by hand through a door. A coil above the fire bed is the usual layout for a wood-fired coil, and keeps the coil length, water volume and pressure drop. |
| C2 | The coil floated in the firebox with no support. | Three brackets of 40 x 40 x 5 mm stainless angle, welded to the shell at the back wall and both ends, pass through slots in the lining; the lowest turn rests on them. | The coil grows about 3 mm when hot; resting on three brackets lets it move. Stainless survives the fire. |
| C3 | The coil could not be put into a welded box, its two tails passed through the wall with no holes, and outside the wall the inlet riser ran through the outlet pipe. | The roof is a separate 3 mm plate, lined with 50 mm board, bolted with 14 M8 bolts to a 25 x 25 mm angle frame round the top of the walls. The coil goes in from the top: held 66 mm toward the back and 30 mm high, then slid forward so its tails pass out through two 40 x 70 mm slots in the end wall, then set down. The tails stop 10 mm outside the wall; gland plates with ceramic rope packing close the slots and let the tubes slide. Unions join the upper tail to a separate outlet pipe to the header, and the lower tail through a reducer to the inlet jumper, which runs up 175 mm in front of the centre line so nothing crosses. | A bolted roof also lets the coil be inspected and replaced. Sliding glands let the coil grow without stressing the wall. Unions keep every joint outside the fire. |
| C4 | The coil inlet ended in mid-air beside the economizer, which was a solid box with no tubes, no fixing and no flue path to the chimney. | The economizer is a 2 mm steel box with a 6 mm base flange on 12 studs welded to the roof, a bolted lid carrying the chimney spigot, and a serpentine of 12.7 mm stainless tube inside (three layers, about 7.3 m bent on a standard 38 mm radius, water in at the top and out at the bottom, so the gas meets colder tube as it rises) resting on two support bars. Bulkhead unions take the tube ends through the end walls. | Counterflow, and 0.29 m² of tube against the 0.22 m² the calculation needs. The lid comes off to clean soot off the tubes. |
| C5 | The firebox stood on the deck with no fixing, and its hot floor sat directly on the deck. | Two skids of 50 x 50 x 3 mm square tube run across the deck, welded under the firebox floor; each end is bolted through the deck into the trailer's side rail with one M12 bolt. | Bolting into the side rails puts the load where a used trailer is strong. The 50 mm air gap keeps the deck cool. |
| C6 | The seal pot reached 50 mm below the deck. Also, as drawn, a 1 m dip leg would have let the header rise to about 0.11 bar, not 0.094 bar, because the water the steam pushes out of the dip leg raises the level outside it, and that water would have overflowed into the vent. | The pot stands on a 10 mm foot plate on the deck. The dip leg ends 890 mm below the static water mark; the 110 mm the outside level rises adds the rest, so the seal still blows at 1.0 m of water, 0.094 bar. The pot top is raised so the highest water level stays 100 mm below it. The header drops from 1600 to 1550 mm to suit. | Keeps the stated seal limit exactly and keeps water out of the vent. |
| C7 | The header was held up only by the coil outlet tube. | A 50 mm square post on a bolted foot plate carries the header on a saddle under two U-bolts; a flat-bar stay holds the seal pot to the post. | The coil tube is not a structure, and it moves when hot. |
| C8 | The diverter had no path to the vent, so its vent position went nowhere. | The diverter moves to the back end of the header; a 1 in vent line runs from its vent port up and over the header into the vent pipe, 110 mm above the pot top. | Steam sent to the vent goes straight up the existing vent pipe, above head height, and nothing can close it. |
| C9 | The relief valve sat 3 mm into the header and discharged at the header with no pipe. | The valve stands on a 3/4 in socket on top of the header; a 3/4 in discharge pipe runs from its outlet up to 2.3 m, open at the top with a drain hole at the low point, tied to the vent pipe by a round-bar stay. | A safety valve must discharge somewhere safe; this matches the open vent's 2.3 m outlet. Set pressure and capacity are unchanged. |
| C10 | The hose ran through the deck edge and 20 cm³ into the hood top. | The hose runs from a coupling on the diverter, clear of the trailer, down to a coupling on top of the hood. | The hose must connect, not pass through things. |
| C11 | The hood inlet stub did not reach the manifold, the manifold floated, and the skirt butted the hood's bottom edge with nothing joining them. | A riser pipe tees into the manifold, passes up through the hood and carries a flange and the hose coupling on top; two straps hang the manifold from the inner skin. The skirt is a 100 mm band riveted round the outside of the hood, lapping it by 40 mm, with 60 mm below. | Every joint is now riveted, welded or bolted. The 60 mm skirt depth is unchanged. |
| C12 | The feed drum's cradle was a solid block that cut through the drum, and there were no feed lines. | Two hardwood saddles with a curved top, bolted to the deck, and two ratchet straps hold the drum. A suction hose runs from the drum outlet to the pump; a 12.7 mm stainless feed line runs from the pump up the back end of the firebox in two clips to the economizer inlet. | A drum must be held down for towing; the water has to get from the drum to the coil. |
| C13 | The pump stood alone; the battery and alarms were not drawn. | One pump and alarm box on the deck holds the pump, the 12 V battery and the alarm controller, wired as the build plan shows. | Keeps the 12 V parts together, dry and away from the fire. |
| C14 | The door was a plate on a closed wall, with no hinges or latch; the damper was a block. | A 3 mm door with a 46 mm fibre board plug, two lift-off hinges and a turn latch; a 3 mm slide damper in two guides. | Buildable from sheet and bought hardware. |

*Table 2. Knock-on changes.*

| Item | Change | Reason |
| --- | --- | --- |
| Efficiency and wood use | Fuel-to-steam efficiency 51.4 % (was 53.5 %); wood 10.5 kg/h (was 10.1 kg/h) and 5.6 kg/m² at 15 cm (was 5.4 kg/m²). R4 and R5 stay not met; their gaps widen by about 2 points. | The taller firebox has 36 % more wall, so it loses 3.5 kW through the lining instead of 2.6 kW. The coil itself is unchanged. See A1. |
| Pressure | Coil inlet 0.108 bar (was 0.110 bar); header 0.033 bar and seal limit 0.094 bar unchanged. | Shorter outlet riser to the lower header. |
| Mass | Towed with the drum and seal drained 468 kg (was 402 kg), full 602 kg (was 536 kg); R11 mass still met, 32 kg under 500 kg. Width unchanged at 1.48 m. | Firebox 125 kg (was 98 kg); 41 kg of skids, post, brackets, stand, glands, lines and frames added. |
| Cost | BOM lines 5 and 6 repriced and lines 17 to 21 added: USD 2,275 (was USD 1,915), USD 75 over the USD 2,200 value-engineering target. | Parts added for construction. |
| Drawings | STR-DWG-002 Rev P3; making sketches STR-DWG-101 to 121 added. | Follows the model. |
| Documents | STR-CAL-001 v0.3, STR-REQ-001 v0.5 and STR-PRC-001 v0.5 updated for the figures above. No requirement changed status. | Follows the model. |

*Table 3. Proposed, then accepted by Amish as recommended on 2026-10-02.*

| # | Question | Options | Recommendation |
| --- | --- | --- | --- |
| A1 | The taller firebox costs about 2 points of efficiency. | (a) accept for the first prototype; (b) 75 mm lining with the box made 50 mm larger each way, which brings efficiency back to about 53.8 % for about 8 kg more; (c) fold the firebox shape into the R5 evaporator bank study (STR-DDR-002, item 1), which reshapes the flue anyway. | (c), keeping (a) for now. Accepted 2026-10-02. |
| A2 | The seal pot level rises as steam condenses in it and falls as it boils off; an overfilled pot raises the seal limit. | (a) an overflow pipe at the static water mark, draining to the ground; (b) a level mark and top-up by hand only, as now. | (a): it fixes the seal depth so it cannot be overfilled. It is a change to the safety case, so it is proposed, not made. Accepted 2026-10-02: the overflow is piped down to ground level at the back of the trailer, away from the operator's side. It is to be added to the model and build plan (follow-up). |
| A3 | The relief valve discharge now goes up to 2.3 m. | (a) keep it, as modelled; (b) discharge down to the ground at the front of the trailer. | (a), subject to the boiler authority's ruling. Accepted 2026-10-02, subject to the authority's ruling. |

## Consequences

- `design_state: constructable` in `project.yaml`. The build plan STR-BLD-001 (`docs/05-build-plan.md`) shows every component and step in pictures drawn from the model (`cad/src/build_plan_media.py`). Decisions are recorded in the design decisions register, STR-DEC-001 (`docs/06-design-decisions.md`), which accepted this record on 2026-10-02.
- Requirement status is unchanged in kind: 2 not met (R4, R5), 3 at risk (R2 twice, R11 width), 1 not verifiable at TRL 3 (R1), 8 met; R12 is reported against the value-engineering target, USD 75 over (STR-CAL-001 v0.3).
- The appearance model `cad/src/product_model.py` was brought into line with the constructable design on 2026-10-02 and its render scenes exported. The photoreal renders (`media/render-*.png`), `media/card.png` and `media/social-preview.png` are rendered from those scenes on Amish's Mac, where Blender is.
- The trailer is bought used. Its side rails must be checked for the skid bolts when it is chosen; the drawings assume 80 mm rails.

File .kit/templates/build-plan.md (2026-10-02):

---
doc_id: PRJ-BLD-001
title: Project prototype build plan
project: Project name
doc_type: Build plan
version: "0.1"
status: Draft
date: YYYY-MM-DD
author: Amish Chadha
license: CERN-OHL-S-2.0
revisions:
  - version: "0.1"
    date: YYYY-MM-DD
    author: Amish Chadha
    change: First build plan; design made constructable
---

# Project prototype build plan

**Plan, not yet built.** How to build the first proof-of-concept prototype, component by component. Building and testing to it is TRL 4 work. Decisions still to be made are kept in the design decisions register (`docs/06-design-decisions.md`), not here.

## 1. What you are building

Every component, pulled apart and numbered in build order

One short paragraph: what the prototype is, how many components, which are made and which are bought, and the main ways they are made.

## 2. What changed to make it buildable

| Component | The concept had | The buildable design has | Why |
| --- | --- | --- | --- |

## 3. Making the components

### 3.1 Component name

Making sketch

**What it is and what it is made from.**

**How to make it.**

1. Mark out ...
2. Cut ...

**How it fits the parts next to it.**

Close-up of the joint

**Check before moving on.**

## 4. Putting it together

### Step 1: ...

Step 1

## 5. First checks

| Check | Requirement | How | Pass when |
| --- | --- | --- | --- |

## 6. Safety stops

## 7. Tools, skills and workspace

## 8. Where the numbers come from

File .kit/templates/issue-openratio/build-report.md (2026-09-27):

---
name: Build report
about: Tell us what happened when you built, printed or tested part of this design
title: "Build report: "
labels: build-report
---

This is a research and educational prototype, not a medical device. It is a TRL 3 concept and is not released for fabrication. If you build any part of it, you do so at your own risk. Reports help everyone.

**What you built** (part, sub-assembly or test)

**Materials, tools and settings**

**What worked**

**What did not work, with photos or measurements if you have them**

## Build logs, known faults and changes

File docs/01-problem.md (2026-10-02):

---
doc_id: STR-PRB-001
title: SteamRoot problem statement
project: SteamRoot
doc_type: Problem statement
version: "0.5"
status: Draft
date: '2026-10-02'
author: Amish Chadha
license: CERN-OHL-S-2.0
revisions:
- version: "0.1"
  date: '2026-09-24'
  author: Amish Chadha
  change: Initial scaffold
- version: "0.2"
  date: '2026-09-24'
  author: Amish Chadha
  change: Populate to TRL 2 (users, context, constraints, out of scope, prior work, safety)
- version: "0.3"
  date: '2026-09-25'
  author: Amish Chadha
  change: Record Amish's 2026-09-25 decisions on first users, first jurisdiction and budget; regulatory ruling marked as an open prerequisite
- version: "0.4"
  date: '2026-09-25'
  author: Amish Chadha
  change: Recommendations accepted by Amish (DDR-002)
- version: "0.5"
  date: '2026-10-02'
  author: Amish Chadha
  change: "Partners and authority answered by Amish's 2026-10-02 decisions"
---

# SteamRoot problem statement

Steaming soil kills weed seeds and soil-borne pathogens without herbicides or fumigants, but the equipment that does it is sized, priced and fueled for large greenhouse operations, so small organic growers who need it most rarely have access to it.

## The problem

Organic and low-input growers fight weeds and soil-borne disease (damping-off, Fusarium, Pythium, Rhizoctonia, root-knot nematodes) with hand weeding, cultivation, rotation and, where allowed, fumigants. Hand weeding is often the largest labor cost on a market garden. Chemical soil fumigants are restricted or banned for organic growers, and methyl bromide has been phased out for most uses under the Montreal Protocol.

Heating soil to about 70 °C (158 °F) for 20 to 30 minutes kills most weed seeds and pathogens while sparing some of the heat-tolerant beneficial organisms. Steam is the traditional way to deliver that heat because condensing steam releases a large amount of energy (about 2.26 MJ per kilogram) right where it condenses. The barriers are equipment and energy:

- Commercial soil steamers are built around diesel, oil or gas boilers sized for greenhouse ranges and nurseries. They are costly to buy and to fuel.
- Many small growers have surplus woody biomass (prunings, hedgerow wood, pallets) but no safe way to turn it into steam.
- Improvised rigs built from pressure cookers, water heaters or sealed tanks are dangerous. A sealed vessel with a fire under it can fail violently.
- Energy per square meter is high, so an inefficient boiler makes the method too slow and too fuel-hungry to be practical.

## Users and context

| User | Need | Context |
| --- | --- | --- |
| Small organic farm or market garden | Clear weed seed bank and disease from high-value beds without herbicides | Outdoor beds and polytunnels, 0.1 to 2 ha, beds about 0.75 to 1.2 m wide |
| Nursery or seedling grower | Pasteurize potting media and propagation beds | Sheds and greenhouses; generator must stay outside |
| Community garden or farm cooperative | A shared, towable machine that several growers can use | Shared equipment, varied operator experience |
| Extension educator or researcher | An open, documented reference design to demonstrate and study | Field days, trials, university farms |
| Open hardware community | A buildable, inspectable low-pressure steam design | Farm workshops, makerspaces |

## Constraints

- Garage-buildable prototype within $2,200 USD (raised from $1,500 to $1,800 and then to $2,200 by Amish on 2026-09-25 to allow about 15 % contingency over the priced BOM), using stock steel, stainless tube and off-the-shelf safety parts.
- Near-atmospheric operation: open-vented, never sealed, with a normal working pressure well below the thresholds that bring a boiler under pressure vessel and boiler codes. Thresholds, exemptions and registration rules differ by country, state and province and must be confirmed with the local authority before any build.
- Fired with locally available dry woody biomass; no diesel or propane burner.
- Towable by a small tractor, utility vehicle or car with a hitch; 500 kg or less as towed, with the feed tank and seal pot drained and filled on site.
- Operable by one trained adult, with a second person nearby during steaming.
- Outdoor operation only for the fire. Steam may be piped into a greenhouse or polytunnel; the firebox and chimney may not.

> **Safety:** This project handles open fire, flue gas containing carbon monoxide, and steam that causes severe burns. It is a concept, not a buildable or approved design. Steam generators are regulated equipment in many jurisdictions even at low pressure.

## Out of scope

- Any pressurized boiler or sealed vessel. SteamRoot will not operate as a pressure boiler under any configuration.
- Deep steaming beyond 15 cm and field-scale broadacre treatment.
- Negative-pressure (buried pipe) steaming systems.
- Automatic fire control, remote operation or unattended running.
- Chemical additives mixed with steam.

## Prior work

Steam soil disinfestation is established practice. Greenhouse growers have steamed soil since the late nineteenth century, and it remains common in greenhouse horticulture and nurseries. The main methods are:

- **Sheet steaming:** steam is released under a heavy sheet laid on the soil. Simple, but slow and hard to control at depth.
- **Hood steaming:** a rigid open-bottom hood is pressed onto the bed and moved in steps. Better contact and control than sheets. SteamRoot uses this method.
- **Negative-pressure steaming:** steam is drawn down through the soil by suction through buried perforated pipes. Reaches deeper, but needs a permanent installation.
- **Band steaming:** research machines steam only a narrow band where the crop row will be, cutting energy per hectare.

Soil solarization (clear plastic in hot weather) and anaerobic soil disinfestation are lower-energy alternatives, but they depend on climate and take weeks. Steam works in hours and in any season. A 2014 UNEP review of the methyl bromide phase-out called steam "probably the best technical alternative to MB in protected agriculture", but noted that deep in-ground steaming needs long boiler use, labor and fuel that can make it uneconomic ([UNEP Ozone Secretariat, *Phasing-out Methyl Bromide in Developing Countries*, 2014](https://ozone.unep.org/system/files/documents/Phasing-out%20Methyl%20Bromide%20in%20developing%20countries%20FINAL%20low%20version.pdf)). Energy per square meter is therefore the main limit on adoption, which is why SteamRoot focuses on a biomass fire and a flue-gas economizer. The other prior-work statements above are general practice and are not yet individually cited.

## Decisions and open questions

- First users: one market garden and one nursery. Decided by Amish, 2026-09-25 (STR-DDR-001). Decided by Amish, 2026-10-02: one market garden and one nursery within driving distance of Irving that already steam, solarize or chemically treat soil, found through Texas A&M AgriLife Extension's horticulture contacts. None is named or agreed yet.
- First jurisdiction for the regulatory check: Amish's home jurisdiction. Decided by Amish, 2026-09-25. Decided by Amish, 2026-10-02: Texas; the ruling is asked of the Texas Department of Licensing and Regulation's boiler program.
- **Open prerequisite:** a written ruling from the local boiler authority on whether an open-vented, fired monotube coil is exempt from boiler and pressure vessel rules. Amish approved getting it before TRL 3 detail work. It has not been obtained, so TRL 3 was limited to paper calculations and preliminary drawings.

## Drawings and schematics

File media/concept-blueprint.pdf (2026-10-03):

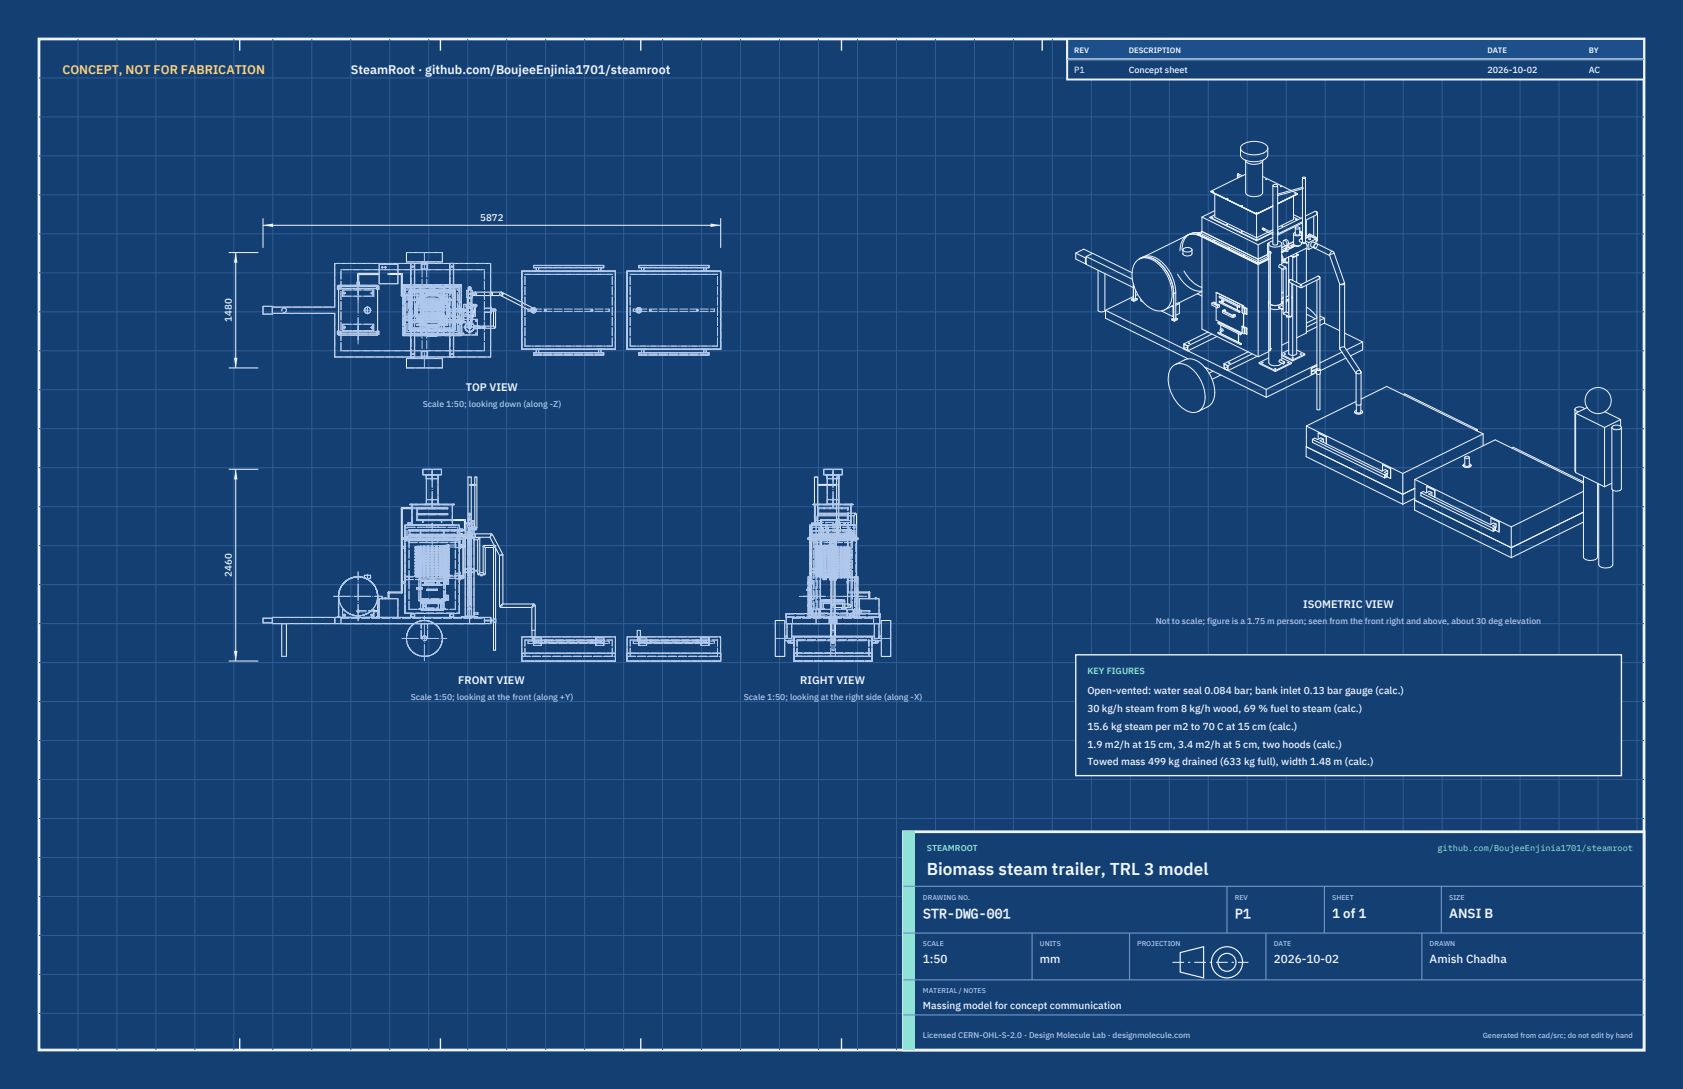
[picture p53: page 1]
CONCEPT, NOT FOR FABRICATION; SteamRoot · github.com/BoujeeEnjinia1701/steamroot; FRONT VIEW; TOP VIEW; RIGHT VIEW; ISOMETRIC VIEW; REV; DESCRIPTION; DATE; Concept sheet; STEAMROOT; github.com/BoujeeEnjinia1701/steamroot; DRAWING NO. STR-DWG-001; REV P1; SHEET 1 of 1; SIZE ANSI B; SCALE 1:50; UNITS mm; PROJECTION; DRAWN Amish Chadha; Licensed CERN-OHL-S-2.0 · Design Molecule Lab · designmolecule.com; Generated from cad/src; do not edit by hand

Scale 1:50; looking down (along -Z)

Not to scale; figure is a 1.75 m person; seen from the front right and above, about 30 deg elevation

KEY FIGURES
Open-vented: water seal 0.084 bar; bank inlet 0.13 bar gauge (calc.)
30 kg/h steam from 8 kg/h wood, 69 % fuel to steam (calc.)
15.6 kg steam per m2 to 70 C at 15 cm (calc.)
1.9 m2/h at 15 cm, 3.4 m2/h at 5 cm, two hoods (calc.)
Towed mass 499 kg drained (633 kg full), width 1.48 m (calc.)

Scale 1:50; looking at the front (along +Y)

Scale 1:50; looking at the right side (along -X)

Biomass steam trailer, TRL 3 model

MATERIAL / NOTES
Massing model for concept communication

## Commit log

2026-09-24 Initial scaffold: standard open hardware layout, CERN-OHL-S v2 + MIT licenses
    Claude-Session: https://claude.ai/code/session_01XuhhSU4W6fYhgCfURbrkut
    [bom.csv]
2026-09-25 Adopt portfolio kit v1.3.0: session commands, scale figure, 3D viewer, flow diagrams
    Adds .claude/commands (/populate, /advance-trl3, /rein-in, /refresh-media)
    so every Claude Code session starts from the standard prompts, and extends
    concept media with a 1.75 m scale figure, an interactive glTF viewer and
    system or energy flow diagrams. TRL cap 3 unchanged.
    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
2026-09-25 Kit v1.3.1: renderer fixes from the TremorTrace pilot
    Context scale parts for small objects, cutaway exclusions, and text
    labels in flow diagrams.
    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
2026-09-25 Populate steamroot to a strong TRL 2 with concept media (batch 1)
    Problem, requirements and precis v0.2, massing model and concept media,
    indicative BOM, docs/REVIEW.md with decisions proposed and awaiting Amish.
    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
    [bom.csv]
2026-09-25 Advance steamroot to TRL 3 (batch 1)
    Decisions approved by Amish 2026-09-25 recorded in DDR-001. TRL 4 is on hold.
    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
    [bom.csv, steamroot-coil.step, steamroot-coil.stl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]
2026-09-26 Accept all recommendations (DDR-002), switch footer to designmolecule.com, add README write-up with new inspiration point
    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
    [bom.csv, steamroot-coil.step, steamroot-firebox.step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]
2026-09-27 Product appearance model and photoreal renders
    Adds cad/src/product_model.py (appearance model for renders only, all main
    dimensions from model.py) and Blender renders in media/render-*.png,
    captioned with the project, repository and viewing direction. README leads
    with the product render; trl stays 3.
    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
2026-10-01 Image quality pass: legible exploded views, flow diagrams and drawing sheets
    Kit 1.6.1 image layout: the parts list sits in its own column, number bubbles sit on visible parts and never overlap, small parts get a leader, pictures are cropped to the subject, flow labels keep numbers with their units, and sheet captions and the revision table no longer overprint. Concept images, blueprint and general arrangement sheet regenerated; repo-specific labels moved clear of other text and lines.
2026-10-02 Kit 1.7.0: constructable design, illustrated build plan and design decisions register
    The design is now constructable: every part can be made and fits its neighbours, with each change recorded in a Design for construction decision record (made under Amish's 2026-09-30 instruction; ope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
    FlexHand also credits Dr. Geeti Chadha as a contribut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
    [bom.csv, steamroot-coil.step, steamroot-coil.stl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]
2026-10-02 Record Amish's approval of the open-decision recommendations
    Amish approved the recommendation on every open decision in the design decisions register ("i approve your recommendations for all 555 open decisions.", 2026-10-02). Each decision is moved to Decisio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
2026-10-03 Carry approved follow-ups into the design and redo photoreal renders
    Amish approved the follow-up actions from the open-decision sign-off ("APPROVED CHANGES, COMPLETE THESE", 2026-10-02), the design-for-construction change tables in ten repos, the last wave's open dec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
    [bom.csv, steamroot-bank.step, steamroot-bank.stl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]
2026-10-03 Record Amish's 2026-10-03 decisions; FlatTrike fork and PotPress guard fixes
    Amish, 2026-10-03: "PalletPilot - i accept it"; "FlatTrike - i accept your design recommendation, proceed and execute the solution for fork direction or caster"; "PotPress - move forward with the four guard fixes. I accept the cost."; "GravitySort - i accept your recommendation"; "TIght Margins - i accept the margins"; "Cost over target - i accept all the cost variations and overruns". FlatTrike knuckle forks turned to trail (35 mm trail); PotPress finer mesh, small-hole plates, top beam and crank bracket covers, ISO 13857 desk check now met on paper. Registers, requirements, drawings, pictures, renders and PDFs upd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
2026-10-28 Kit 1.9.1 upgrade: pipeline documents and detailed CAD for every option
    Kit 1.9.1 installed (.kit, CLAUDE.md, .claude/commands). Kit 1.8 pipeline: STEM check with fixes under the 2026-10-23 standing instruction, concept options with the current design as option A, URS, PRS, generated RTM, REG, FEA, RSK with design FMEA, MKT, PLN and DDR; kit 1.9 D3 model of every option passing cad/fidelity.json; independent review recorded in the STEM check. Amish's 2026-10-25 decisions recorded where he approved a recommendation; all others proposed, awaiting Amish. Product renders and the options picture follow in a later commit where not yet included.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
2026-10-29 Add the concept options picture rendered from the D3 option models
    media/options.png from Blender Cycles panels of every option, rendered on Amish's Mac; the label reads CURRENT DESIGN unless project.yaml records Amish's choice. Clears the docs check, which needs th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

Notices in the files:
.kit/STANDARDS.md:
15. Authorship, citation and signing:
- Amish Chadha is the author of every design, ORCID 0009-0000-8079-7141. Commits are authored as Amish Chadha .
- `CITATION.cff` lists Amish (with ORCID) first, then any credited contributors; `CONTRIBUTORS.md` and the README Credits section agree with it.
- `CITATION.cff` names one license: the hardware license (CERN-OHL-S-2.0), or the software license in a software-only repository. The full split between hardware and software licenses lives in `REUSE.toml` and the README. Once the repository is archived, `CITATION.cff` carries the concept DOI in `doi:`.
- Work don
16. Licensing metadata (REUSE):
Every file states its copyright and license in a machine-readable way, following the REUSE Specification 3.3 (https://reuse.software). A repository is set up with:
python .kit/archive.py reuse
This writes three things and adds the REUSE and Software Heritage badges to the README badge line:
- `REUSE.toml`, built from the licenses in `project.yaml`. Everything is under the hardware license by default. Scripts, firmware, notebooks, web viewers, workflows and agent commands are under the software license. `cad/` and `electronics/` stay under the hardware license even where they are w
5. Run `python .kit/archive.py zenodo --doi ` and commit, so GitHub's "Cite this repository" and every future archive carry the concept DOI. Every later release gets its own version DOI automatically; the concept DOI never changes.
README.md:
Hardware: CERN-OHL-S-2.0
